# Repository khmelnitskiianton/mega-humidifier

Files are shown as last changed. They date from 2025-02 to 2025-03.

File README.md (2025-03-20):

# mega-humidifier



Проект умного увлажнителя воздуха.

Сделан для курсов "Практикум по цифровому производству" и "Микроконтроллеры" в МФТИ ФРКТ 4 семестр.

**Команда:**

- Хмельницкий Антон Б01-306
- Шилов Артем Б01-306
- Багацкий Дмитрий Б01-301

**Медиа:**

- [Github](https://github.com/khmelnitskiianton/mega-humidifier)
- [Telegram Channel](https://t.me/vapegoida)

Poster

## Цель проекта

Разработка автоматического увлажнителя для улучшения микроклимата в квартире

## Задачи проекта

1. Изучить теоретическую литературу по данному вопросу.
2. Изучить существующие аналоги.
3. Продумать и создать модель испарителя.
    + Разработать конструкцию данного устройства и необходимые элементы взаимодействия с окружающей средой.
    + Провести расчеты характеристик модели.
    + Подобрать нужные материалы.
    + Собрать модель.
4. Провести испытание полученного устройства.
5. Рассчитать производительность и КПД устройства с помощью данных полученных
экспериментально.
6. Улучшить устройство с учётом ошибок начальной версии.
7. Разработать технику безопасности и инструкцию по пользованию прибором.
8. Сравнить характеристики самодельного прибора с магазинным экземпляром.
9. Сделать выводы, продумать дальнейшее усовершенствование модели.

## Инструкция/Функционал:

1. Включить в сеть электропитания.
2. Проверить экран на наличие вывода данных и включения вентилятора и испарителя. 
3. На экран выводится: реальное время, примерное время окончания работы цикла
увлажнителя, показания влажности и температуры.
4. Запуск увлажнителя - фиксированное время. На паузу увлажнителем можно поставить нажатием кнопки, чтобы
продолжить работу нужно нажать её повторно. В это время будет выводится только реальное время и статус - “Пауза”.
5. Изменение скорости работы вентилятора и мощности испарения происходит за счет вращательного регулятора и тумблера.
6. По окончанию работы выводится сообщение об окончании и звучит оповещающий сигнал. Чтобы перезапустить увлажнитель и начать новую сессию, нужно нажать один раз на белую кнопку.

## Практическая часть

### Электрическая (модульная) часть

**Схема питания модулей:**

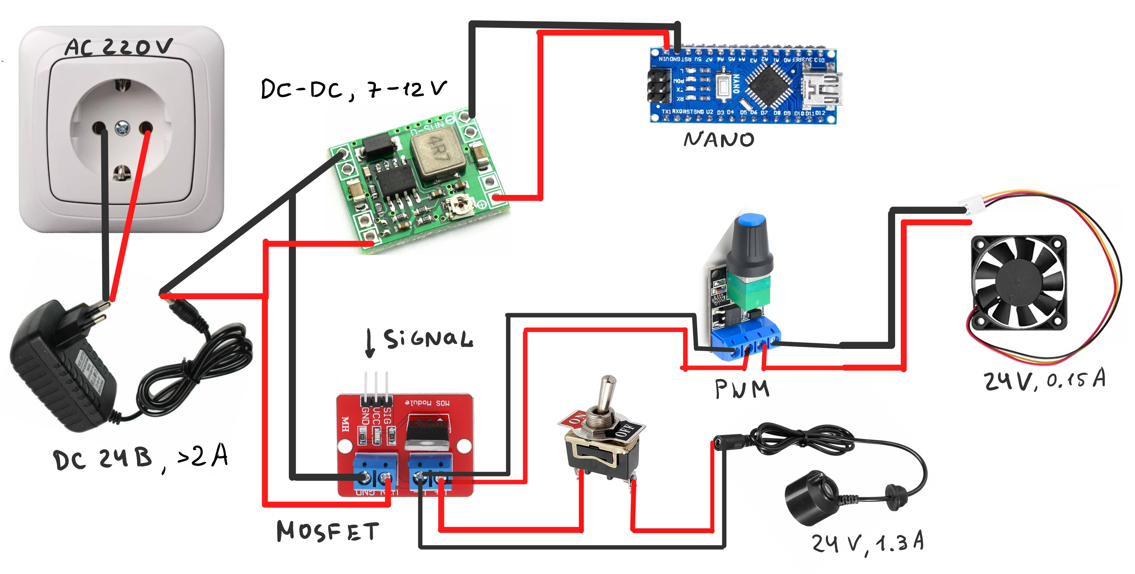
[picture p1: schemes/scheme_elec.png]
Схема питания


**[Схема](./schemes/scheme_arduino.fzz) (выполнена в Fritzing) подключения датчиков к Arduino Nano(лежит в `schemes/`):**

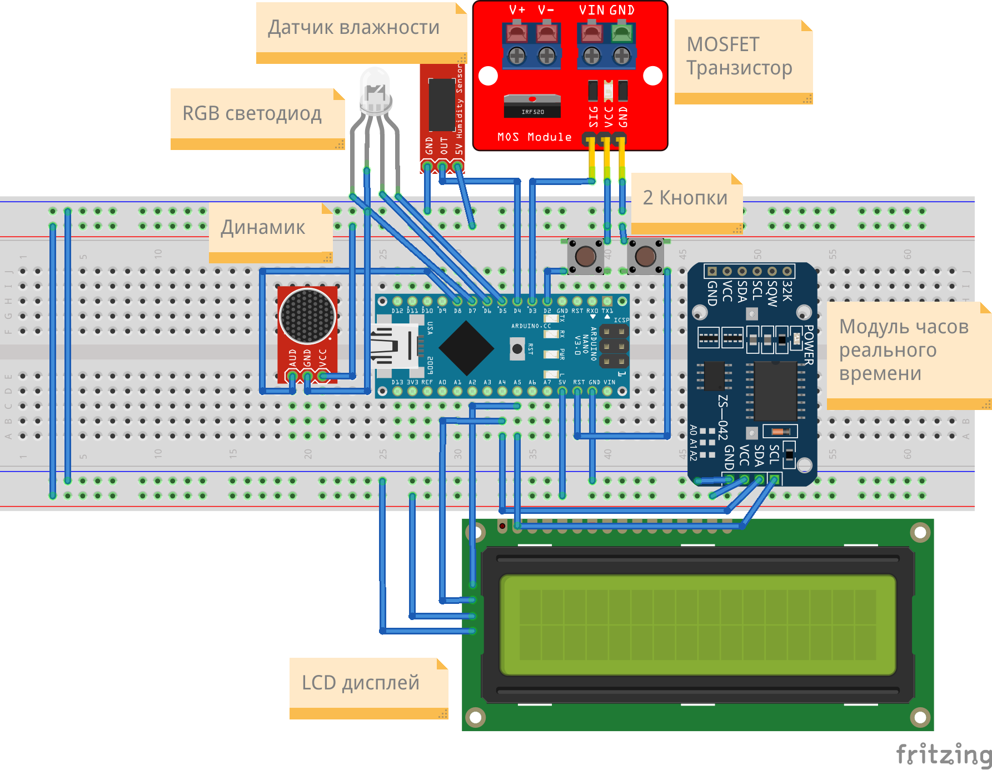
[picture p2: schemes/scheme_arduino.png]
Подключение датчиков


Питание всех модулей осуществляется через блок питания AC/DC IN: 100-200В, OUT: 24В & >2А.

Испаритель воды получает 24В (номинальные) при этом питание регулируется через тумблер. Также подача питания на него регулируется MOSFET транзистором. На вентилятор подается 24В через ШИМ и MOSFET транзистор.

Используется понижающий преобразователь DC-DC (в данном случае с 24В до 7-12В) для питания Arduino Nano .

**Датчики и элементы:**

+ Блок питания 24В, >2А
+ Arduino Nano
+ Вентилятор 24В (60x60x25)
+ Ультразвуковой испаритель 24В
+ Светодиодный модуль KY-016
+ Звуковой модуль KY-006
+ MOSFET транзистор IRF520N
+ ШИМ регулятор XK-1074
+ Тумблер ON-OFF (2A+ 24V+) 
+ Датчик влажности DHT11
+ Тактовая кнопка KY-004 x2
+ DC-DC преобразователь MP1584
+ Модуль реального времени RTC DS3231
+ Дисплей LCD 2004 I2C
 
[Код](./scripts/main/main.ino) прошивки выполнен в программе Arduino IDE(исходный код в `scripts/main/`).

**Использовались библиотеки(лежит в `libs/`):** 

- [для модуля часов реального времени RTC](https://github.com/adafruit/RTClib/releases/tag/1.14.2)
- [для датчиков влажности](https://istarik.ru/blog/arduino/35.html)
- [для дисплея с шиной I2C](https://iarduino.ru/file/134.html)
- [для использования шины I2C(стандартная)](https://docs.arduino.cc/language-reference/en/functions/communication/wire/)

**Основные функции и задачи Arduino:**

1. Управление работой увлажнителя (а именно испарителя и вентилятора) с помощью MOSFET транзисторов.
2. Создание интерфейса для более удобного управления пользователем увлажнителя с
помощью вывода информации на дисплей и управления модулями с помощью кнопок и регуляторов.
3. Измерение и мониторинг показателей микроклимата в квартире (влажность и
температура).
4. Контроль работы с помощью индикации, а также сигнализировании пользователя о завершении работы с помощью звукового модуля.

**Описание кода:**

1. Использованные библиотеки: для датчика влажности (`stDHT.h`), для дисплея
(`LiquidCrystal_I2C.h`), для модуля часов реального времени (`RTClib.h`) и
стандартная библиотека (`Wire.h`).
2. Для большинства модулей написаны отдельные функции: для датчика влажности,
для MOSFET и пьезоэлемента, для модуля часов реального времени.
3. Процесс представляет из себя лимитированная по времени сессия работы. В коде
прописывается время продолжительности работы и автоматически после
определенного времени увлажнитель отключает нагреватель и выводит на экран
надпись `END OF SESSION. PRESS <RESET>`. Чтобы обновить сессию и
заново запустить процесс, нужно нажать на отдельную кнопку Reset.
4. В процессе работы увлажнителя на дисплей выводится реальное время и показания
влажности и температуры, а также время до конца сессии (работы увлажнителя).
Также есть индикация (светодиод), который светит красным цветом или зеленым в
зависимости от того оптимальная ли влажность или нет. Границы также
можно указать в коде.
5. Реализована функция "Паузы", т.е. можно нажатием кнопки Button приостановить
(и продолжить повторным нажатием) работу испарителя и вывод данных на
дисплей. Таким образом можно остановить работу увлажнителя простым нажатием
кнопки на неопределенное время. В процессе паузы выключены реле, светодиод
горит синим цветом и на дисплее выводится надпись `PAUSE` и время с количеством оставшегося времени.

Параметры для настройки работы увлажнителя находятся в [setup.inc](./scripts/main/setup.inc), можно настроить:

- Время работы увлажнителя.
- Минимальную/максимальную допустимую влажность.
- Длительность и тон писка.

**Демонстрация электроники:**

[Видео](https://github.com/user-attachments/assets/03b7d397-51f3-43c1-a0f4-bfc7255fe9b3)

### Конструкционная (механическая) часть

**Контейнер:**

Были изучены аналоги увлажнителей и выбран вариант сборки всех частей в
одной ёмкости. Ёмкость представляет из себя пластиковый контейнер, с высокими стенками и
ручками, вместимость - 4.5 литра размером 17.5x17x21 см

В крышке контейнера вмонтирован вентилятор (60x60x15 см) для вентиляции и создания
нагнетания воздуха. Таким образом поток воздуха насыщается водой, проходя через
увлажнитель, и испаряясь выходит из увлажнителя. Также вмонтирована направляющая конструкция(60x60x15 см), чтобы пар выходил под углом 45 градусов.

**Крышка и корпус:**

Электроника размещена в отдельной пластиковом корпусе с вырезом для дисплея и выведенными на бок датчиками и кнопками. 
Кнопки размещены на корпусе и прикреплены винтами М2.5.

Корпус для электроники, а также направляющая конструкция были смоделированы в SolidWorks/Компас3D (исходники в `enclosure/SLDPRT/` и `enclosure/STL/`), а затем распечатаны на 3D принтере. Отверстия вырезались с помощью дремеля или были смоделированы при проектировании корпуса перед печатью.

**Печатная плата:**

Была смоделирована (исходники в `plate/`) печатная плата для сборки всех датчиков с помощью KiCad и FlatCam и вырезана на фрезерном станке Charly4U:

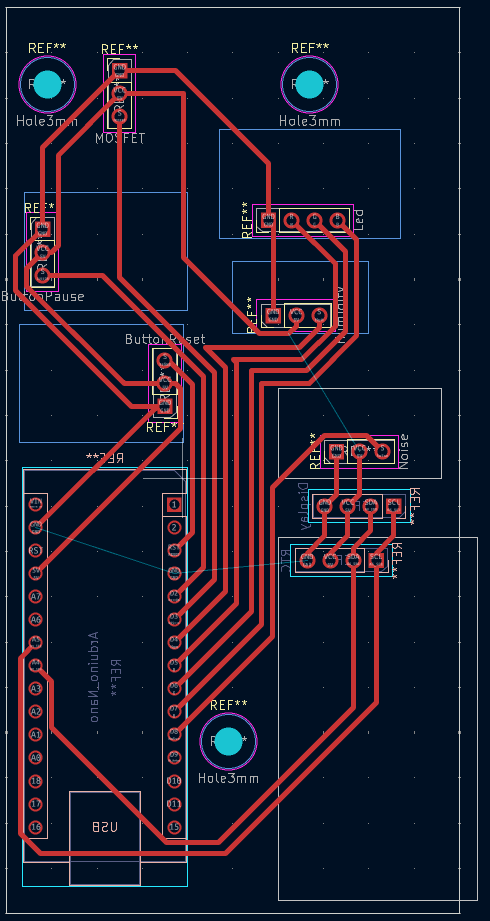
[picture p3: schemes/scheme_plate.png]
Схема платы


- Все датчики монтируются непосредственно либо на плате(односторонняя, но крепятся датчики с двух сторон), либо отдельно проводами.
- Сделаны 3 отверстия для монтажа платы к корпусу винтами M3.

**Таблички с гравировкой**:

Были смоделированы (исходники в `cut/`) таблички с названиями всех элементов на корпусе для упрощения использования устройства в программе CorelDRAW и вырезаны на лазерном станке GCC Spirit GLS40. Затем размещены на корпусе с помощью жидкого клея.

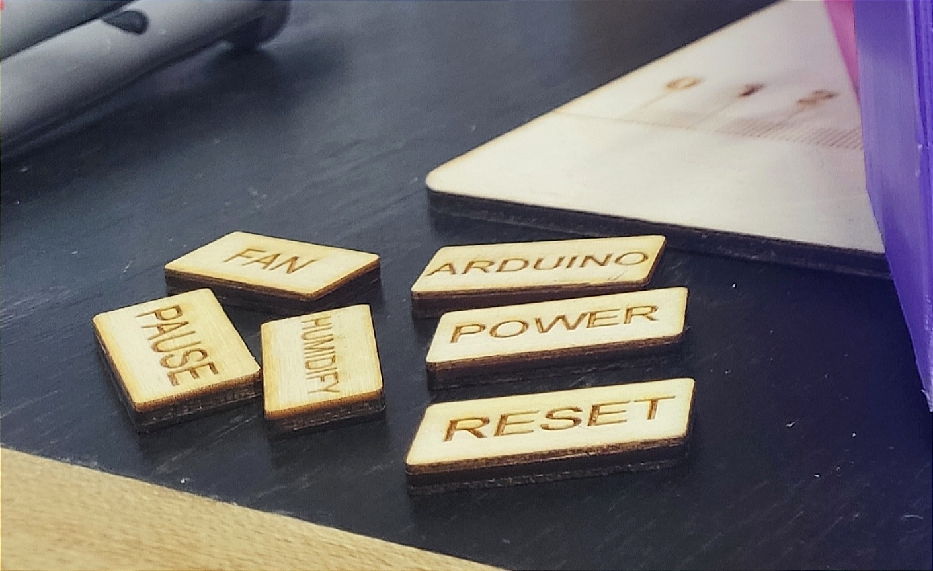
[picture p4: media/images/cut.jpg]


## Процесс сборки

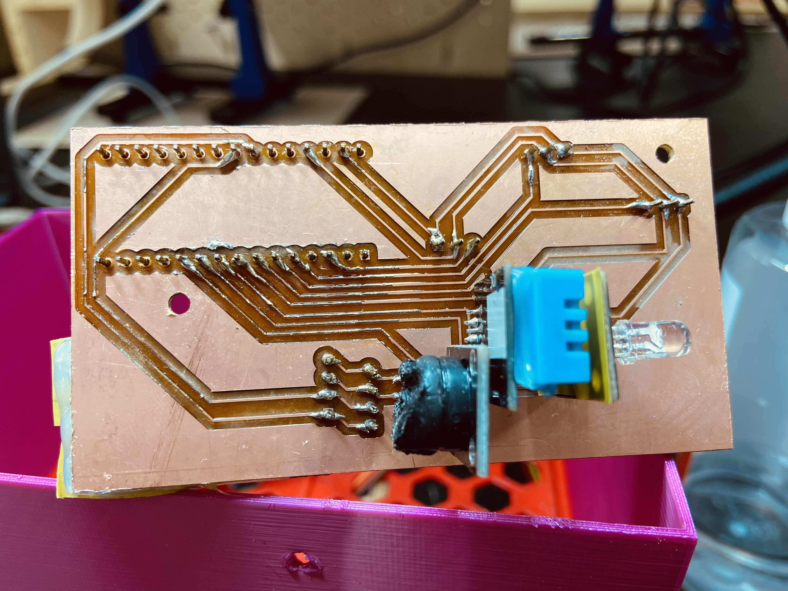
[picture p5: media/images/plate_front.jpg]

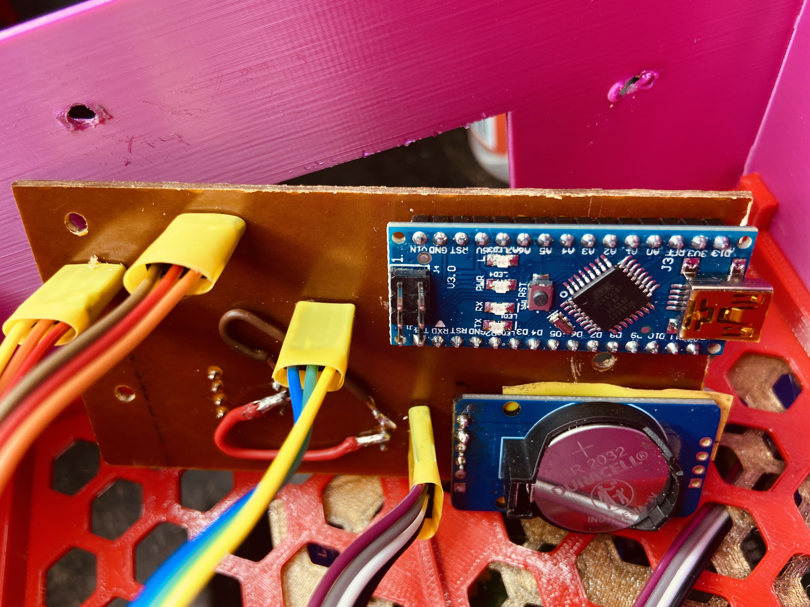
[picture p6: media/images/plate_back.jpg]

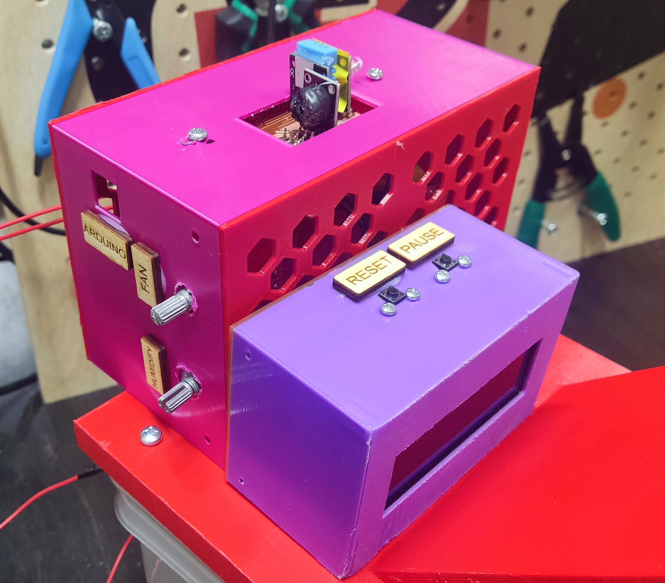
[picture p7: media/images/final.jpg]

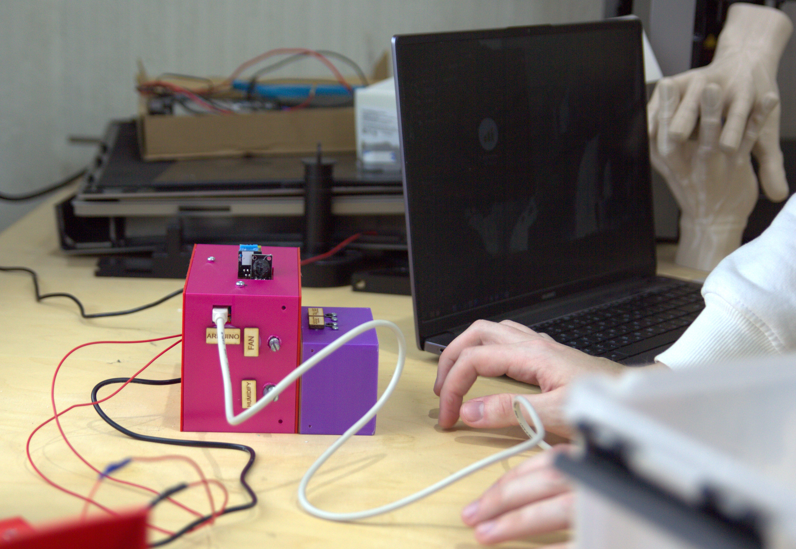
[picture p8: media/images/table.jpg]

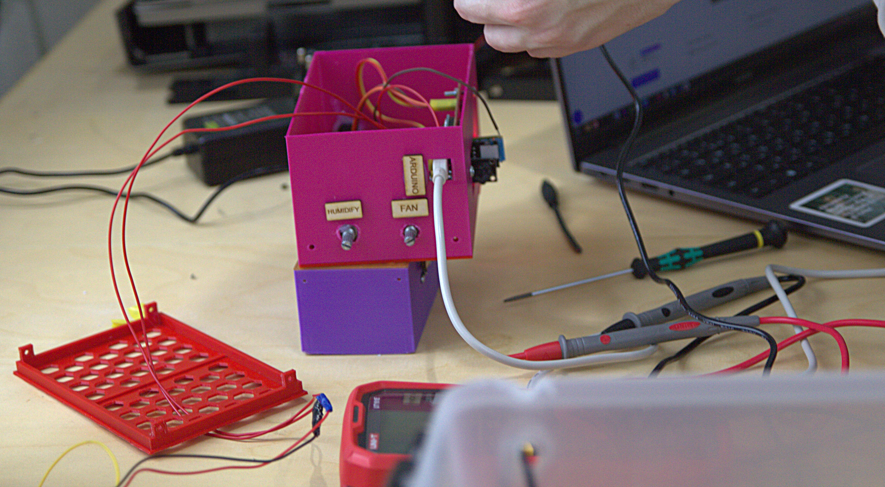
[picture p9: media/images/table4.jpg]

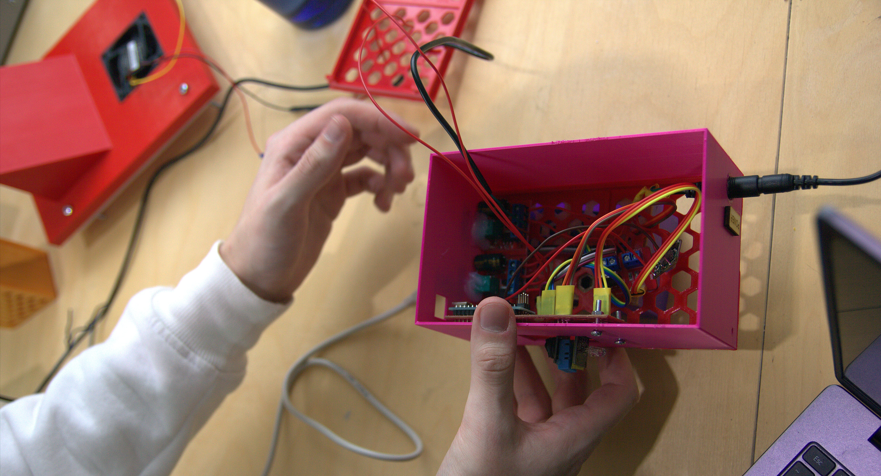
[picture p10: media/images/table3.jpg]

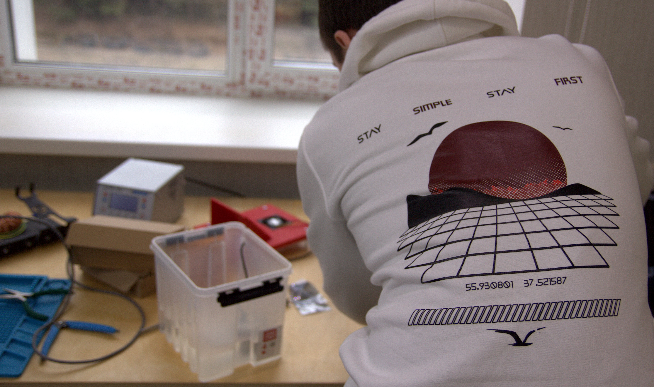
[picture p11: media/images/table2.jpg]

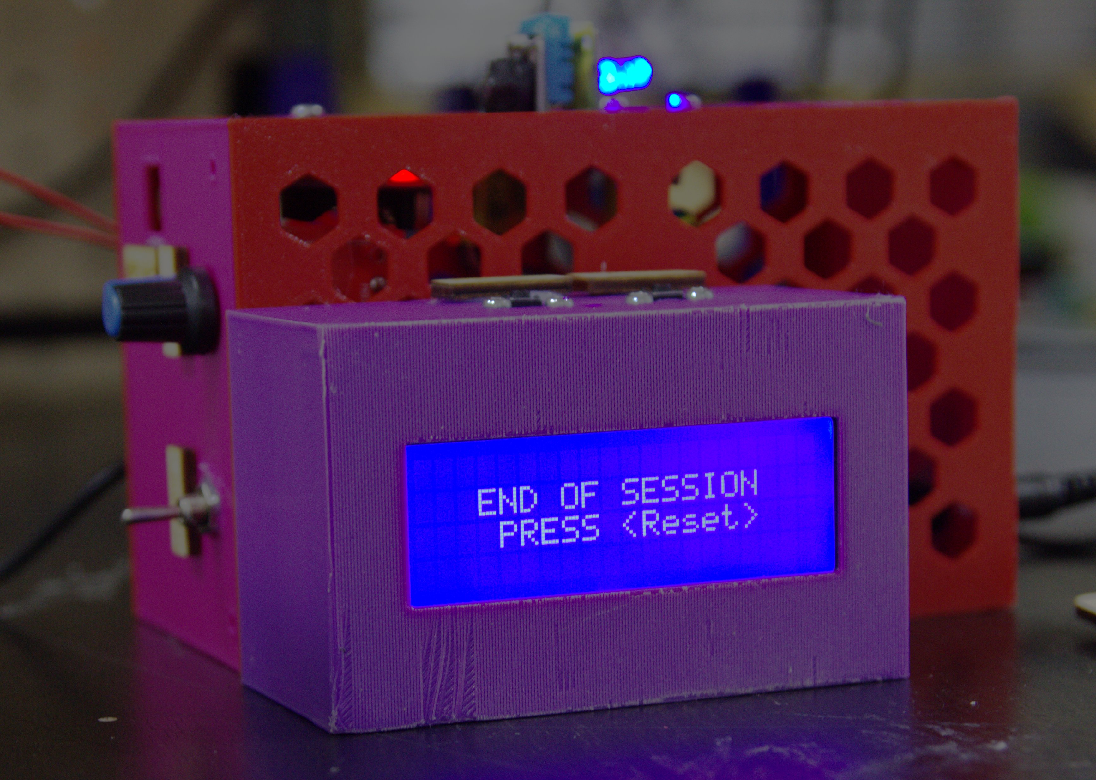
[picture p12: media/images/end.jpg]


**Демонстрация работы(`media/final.mp4`)**:

[Видео](https://github.com/user-attachments/assets/1c645f1c-7396-49a5-b0d6-75ca31a28341)

## Экспериментальный расчет

Производительность парогенератора: 450 мл/ч

Емкость рассчитана на 4.5л, с учетом датчика уровня воды встроенного в парогенератор, эффективный объем воды для испарения 2.5л.

Получаем примерную длительность работы увлажнителя - 5.5ч. 

Рекомендованная настройка работы увлажнителя - 5ч.

## Сравнение с аналогами

Примерная цена всех компонентов: 3500 руб, что меньше чем цена за аналоги с меньшим функционалом.

- [AlexGyver Humidifier](https://github.com/AlexGyver/autoHumidifier) - рядом не стояло.
- [Ivan9073 Youtuber](https://www.youtube.com/watch?v=dj69xXlSA7M) - в подметки не годится.
- [Dzen RMNT.RU](https://dzen.ru/a/ZfLKBk9sOwf64ch5) - слабо.
- [Алексей Федосенко Youtuber](https://www.youtube.com/watch?v=r24A2fugexM) - детский сад.
- [VITEK VT-2348](https://ozon.ru/t/ggRDX7P) - больший функционал, дешевле.

## Результаты и выводы

В ходе разработки автоматического увлажнителя воздуха были выполнены все основные этапы проектирования и сборки устройства.

1. Функциональность устройства

Увлажнитель успешно выполняет свою основную функцию – насыщает воздух влагой с регулируемыми параметрами интенсивности испарения и вентиляции.
Система управления через Arduino Nano позволяет контролировать показатели микроклимата (температуру и влажность), а также задавать параметры работы устройства.
Реализован удобный пользовательский интерфейс с дисплеем, кнопками и регуляторами.
Встроены индикация и звуковой сигнал, что повышает удобство эксплуатации.

2. Эффективность увлажнения

Производительность парогенератора составила 450 мл/ч, что позволяет устройству работать в течение 5,5 часов на одном полном резервуаре (эффективный объем 2,5 л). Также есть возможность расширения объема использовав емкость с большим объемом.
Экспериментальные замеры показали, что устройство способно поддерживать уровень влажности в помещении на оптимальном уровне (40-60%) в зависимости от настроек.

3. Сравнение с аналогами

В сравнении с коммерческими моделями устройство показало схожие характеристики по производительности, но с возможностью гибкой настройки режимов работы.
Стоимость самодельного увлажнителя оказалась ниже аналогичных готовых устройств, что делает проект экономически оправданным.

4. Конструкционные и инженерные решения

Использование 3D-печати позволило создать компактный корпус и направляющую конструкцию для выхода пара.
Электронные компоненты были успешно интегрированы на печатную плату, что упростило сборку и повысило надежность системы.
Устройство собрано из доступных компонентов, что делает возможным его дальнейшее усовершенствование.

5. Возможные улучшения

В будущем можно реализовать автоматическое отключение при достижении заданного уровня влажности.
Возможно добавление управления через Wi-Fi/мобильное приложение для удаленного контроля и мониторинга.
Можно усовершенствовать систему подачи воды, чтобы увеличить время автономной работы.

## Вывод

Созданный умный увлажнитель воздуха соответствует поставленным требованиям и демонстрирует высокую эффективность в поддержании комфортного уровня влажности в помещении. Проект успешно прошел этап испытаний, подтвердил свою работоспособность и может быть доработан в будущем для повышения удобства использования и расширения функционала.

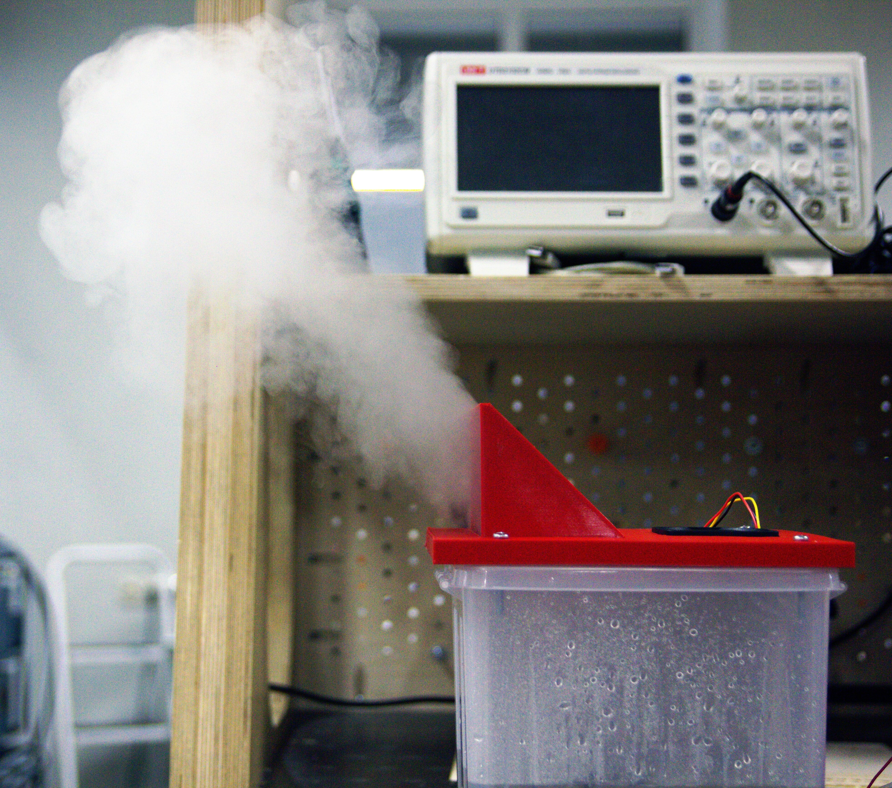
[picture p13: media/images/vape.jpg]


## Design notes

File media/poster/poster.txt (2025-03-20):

(Заголовок):
Автоматический увлажнитель воздуха для поддержания комфортного микроклимата в помещении. Устройство контролирует уровень влажности, регулирует интенсивность испарения и работает по заданному пользователем времени. Компактная конструкция с цифровым управлением делает его удобным в эксплуатации.

Функционал устройства:
• Автоматическое поддержание влажности
• Регулируемая мощность испарителя и вентилятора
• Дисплей с отображением текущей влажности, температуры и времени работы
• Звуковая и световая индикация
• Функция паузы
• Простая перезагрузка работы

Комплектующие:
• Блок питания 24В, >2А
• Arduino Nano
• Вентилятор 24В (60x60x25)
• Ультразвуковой испаритель 24В
• Светодиодный модуль KY-016
• Звуковой модуль KY-006
• MOSFET транзистор IRF520N
• ШИМ регулятор XK-1074
• Тумблер ON-OFF (2A+ 24V+) 
• Датчик влажности DHT11
• Тактовая кнопка KY-004 x2
• DC-DC преобразователь MP1584
• Модуль реального времени RTC DS3231
• Дисплей LCD 2004 I2C

Конструкция:
• Два корпуса для электроники, напечатанный на 3D-принтере
• Контейнер 4,5 л с вмонтированным вентилятором
• Направляющая для выхода пара

Принцип работы:
• Контроль микроклимата – датчик DHT11 измеряет температуру и влажность, передавая данные в систему управления.
• Испаритель и вентилятор – регулируемые питанием позволяют настраивать скорость увлажнения.
• Индикация – дисплей LCD 2004 I2C отображает состояние увлажнителя, а цвет светодиода информирует о статусе работы.
• Автоматическое отключение – по окончании заданного времени устройство выключается и подает сигнал.

Используемые технологии:
• 3D-печать
• Лазерная резка
• Фрезерная резка
• Пайка
• Прошивка микроконтроллера(Arduino)

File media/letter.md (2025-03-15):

# Пояснительная записка к проекту "Умный увлажнитель воздуха"

Github: [https://github.com/khmelnitskiianton/mega-humidifier](https://github.com/khmelnitskiianton/mega-humidifier)

## Автор и состав проектной команды

Проект разработан в рамках курсов "Практикум по цифровому производству" в МФТИ ФРКТ (4 семестр).

### Команда разработчиков:

- Хмельницкий Антон (Б01-306) – работа с микроконтроллером, проектирование и работа с печатной платой.
- Шилов Артем (Б01-306) –  подбор комплектующих, 3D моделирование и печать, организация сборки и тестирования.
- Багацкий Дмитрий (Б01-301) – механическая часть устройства, модулирование в граф. редакторе, работа с ЧПУ и лазерной резкой.

## Причины выбора проекта
 
Уровень влажности в помещении напрямую влияет на здоровье человека и комфорт проживания. Недостаточная влажность может приводить к сухости кожи, проблемам с дыхательной системой, ухудшению состояния растений и мебели. Коммерческие модели увлажнителей воздуха зачастую имеют ограниченный функционал, высокую стоимость или низкую эффективность.

Наш проект предлагает создание автоматического увлажнителя, который будет поддерживать заданный уровень влажности, обеспечивать удобный пользовательский интерфейс и предоставлять больше возможностей для гибкой настройки по сравнению с аналогами.

## Цель и задачи проекта

### Цель

Разработка автоматизированного увлажнителя воздуха с интеллектуальным управлением и возможностью гибкой настройки параметров работы.

### Задачи

- Исследование существующих аналогов и теоретической литературы по теме.
- Разработка модели испарителя, подбор материалов и проведение расчетов.
- Проектирование и сборка схемы питания и управления устройством.
- Разработка программного обеспечения для управления устройством.
- Проведение испытаний и тестирование производительности.
- Оптимизация устройства, исправление недостатков.
- Разработка инструкции по эксплуатации.
- Сравнение характеристик устройства с коммерческими аналогами.

##  Описание устройства

Умный увлажнитель воздуха представляет собой устройство, которое автоматически регулирует уровень влажности в помещении. 

Оно состоит из следующих компонентов:

+ Блок питания: 24В, >2А
+ Контроллер: Arduino Nano.
+ Испаритель: 24В с регулировкой подачи питания.
+ Вентилятор: 24В с ШИМ-регулированием.
+ Датчик влажности и температуры: DHT11.
+ Дисплей LCD 2004 I2C: отображает текущее состояние устройства.
+ Модуль реального времени RTC DS3231: позволяет учитывать время работы и отображать реальное время.
+ 2 кнопки управления, MOSFET транзистор, RGB светодиод: управление работой увлажнителя и индикация состояния.

### Функции устройства:

+ Автоматическое включение и выключение по таймеру.
+ Регулировка интенсивности испарения и скорости вентиляции.
+ Отображение текущих данных на дисплее.
+ Звуковая индикация окончания работы.
+ Возможность временной паузы и ручного управления.

##  Процесс решения поставленных задач

### Электронная часть

Проектирование схемы проводилось с использованием Fritzing.

Код был разработан в среде Arduino IDE. Исходники в `scripts/main/`

Использованы библиотеки:

+ `RTClib.h` – для работы с модулем реального времени.
+ `stDHT.h` – для работы с датчиком влажности.
+ `LiquidCrystal_I2C.h` – для управления дисплеем.
+ `Wire.h` – для работы с I2C-шиной.

Функциональность кода:

+ Чтение данных с датчика влажности и температуры.
+ Управление вентилятором и испарителем через MOSFET.
+ Отображение параметров на дисплее.
+ Реализация режима паузы и индикации.

### Механическая часть

Корпус для электроники и направляющая конструкция для выхода пара были смоделированы в SolidWorks/Компас3D и напечатаны на 3D-принтере. Электронные компоненты размещены в пластиковом корпусе с креплением кнопок и дисплея. Исходники в `enclosure/`

Печатная плата была разработана в KiCad и вырезана на фрезерном станке Charly4U. Исходники в `plate/`

## Анализ аналогов и отличительные особенности

Аналоги на рынке:

+ VITEK VT-2348 – имеет меньший функционал и слабую систему управления.
+ AlexGyver Humidifier – не обладает удобным интерфейсом и дисплеем.
+ DIY-проекты с YouTube – часто не имеют автоматизации и гибких настроек.

### Отличительные особенности нашего устройства:

+ Полноценный дисплей с отображением данных.
+ Гибкое управление скоростью испарителя и вентилятора.
+ Звуковая индикация завершения работы.
+ Возможность временной паузы.
+ Компактный корпус с удобным доступом ко всем элементам.

## Процесс проектирования и изготовления

+ Разработка схемы подключения и выбор компонентов.
+ Проектирование печатной платы в KiCad и её производство.
+ Создание 3D-модели корпуса и печать деталей на 3D-принтере.
+ Создание табличек с гравировкой в CorelDraw и вырезание их на лазерном станке.
+ Сборка устройства, проверка работы всех компонентов.
+ Написание кода управления, отладка программного обеспечения.
+ Проведение тестирования и внесение корректировок.

## Тестирование и анализ результатов

Производительность парогенератора – 450 мл/ч.
Объем резервуара – 4.5 л (эффективно используется 2.5 л).
Время работы – до 5.5 часов на одной заправке.
Оптимальный уровень влажности поддерживается в пределах 40-60%.
Испытания показали, что устройство стабильно работает, поддерживая заданные параметры влажности.

## Выводы

Разработанный умный увлажнитель воздуха полностью соответствует поставленным целям. Он обеспечивает удобное управление, надежную работу и гибкую настройку параметров. По сравнению с коммерческими аналогами, он обладает большим функционалом при меньшей стоимости.

### Потенциальные улучшения:

+ Добавление Wi-Fi-модуля для дистанционного управления.
+ Автоматическое отключение при достижении заданной влажности.
+ Расширение резервуара для увеличения времени автономной работы.
+ Проект успешно завершен, протестирован и может быть использован в реальных условиях.

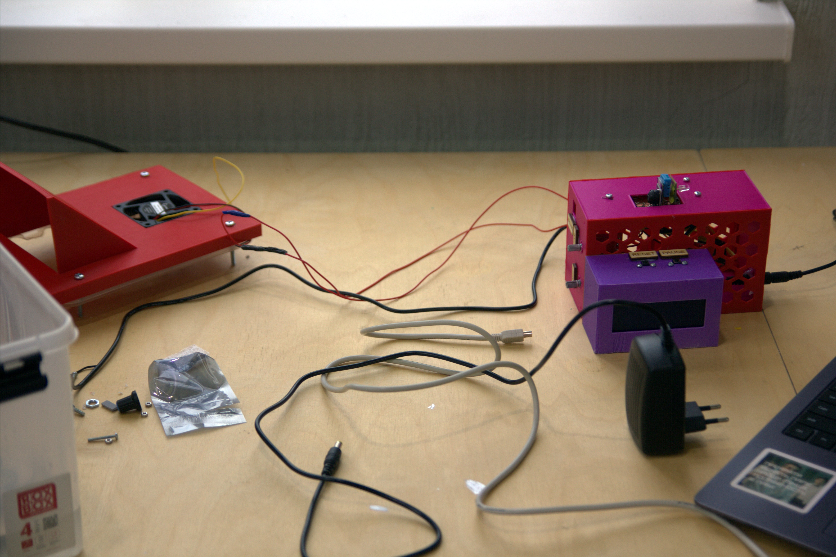
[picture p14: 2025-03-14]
media/images/made.jpg

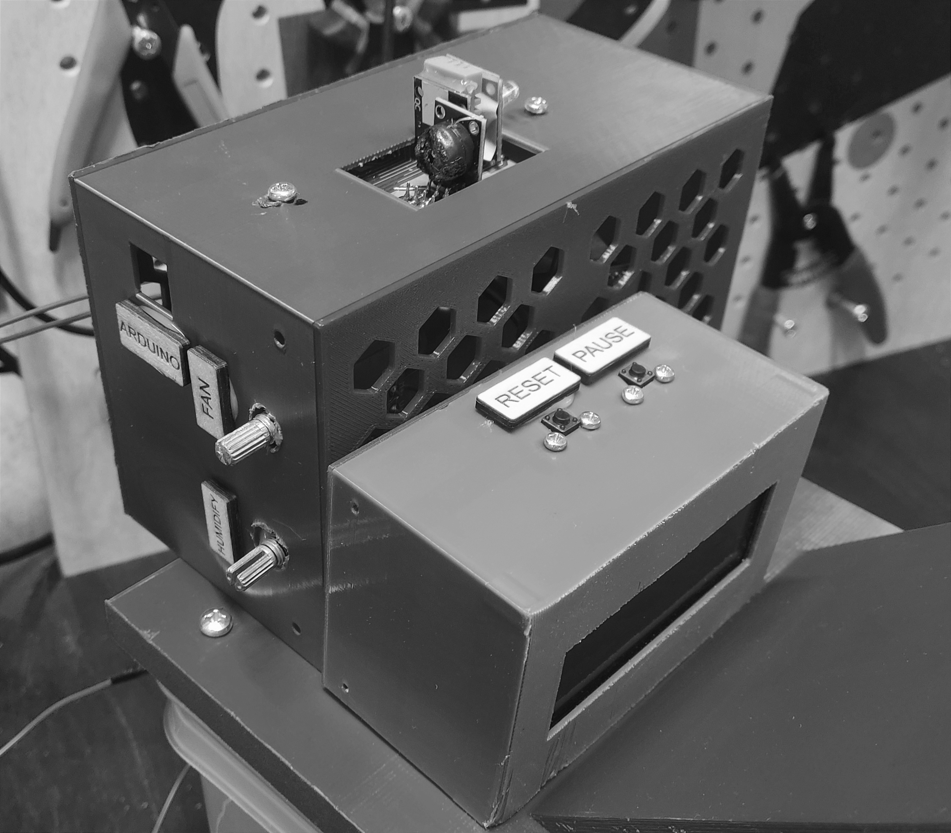
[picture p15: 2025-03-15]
media/images/final_bw.jpg

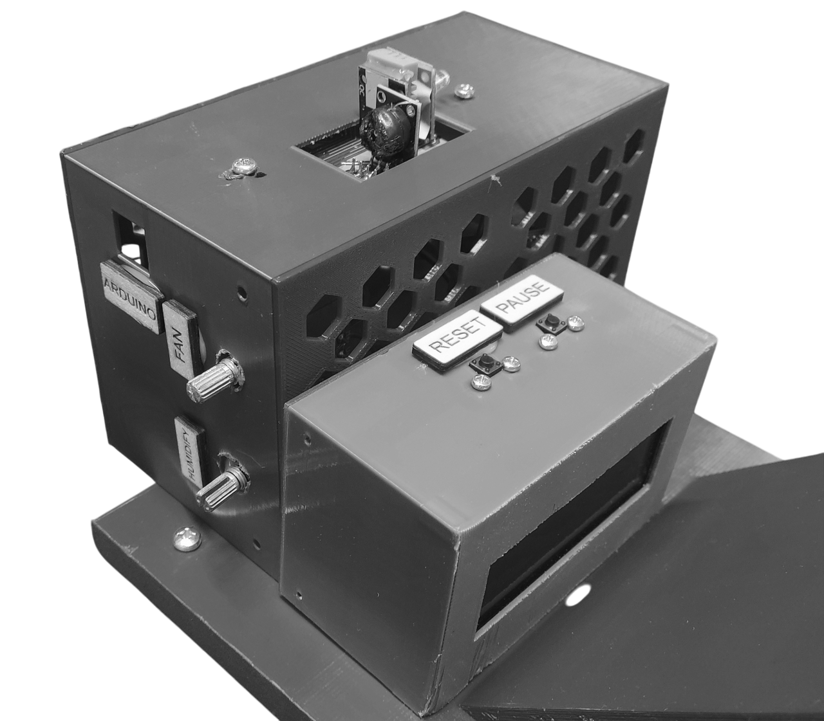
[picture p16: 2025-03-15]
media/images/final_bw_cut.png

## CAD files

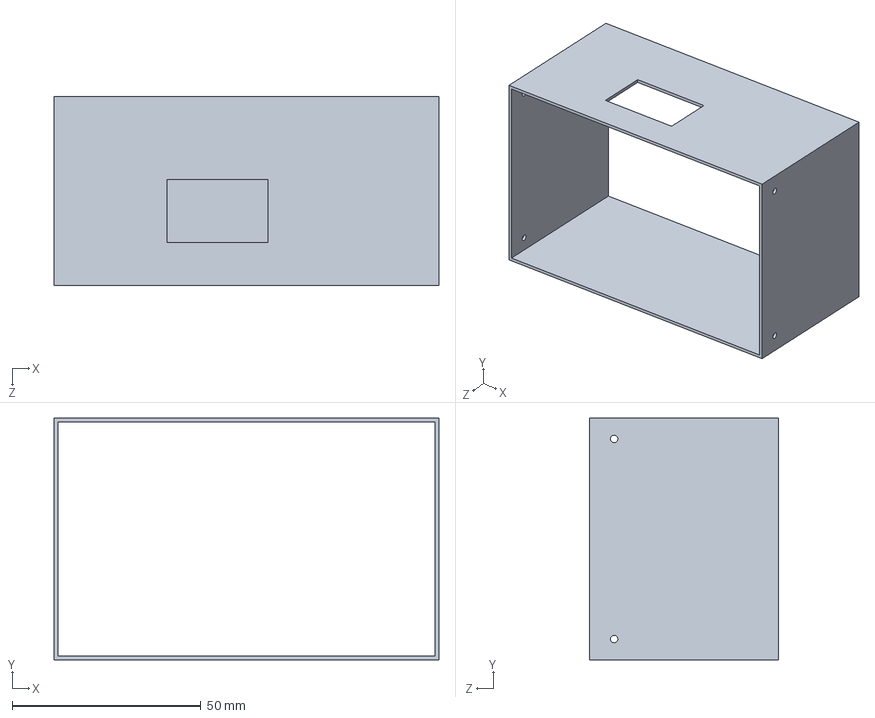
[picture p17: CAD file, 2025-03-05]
enclosure/SLDPRT/box_1.5x_holes.SLDPRT
102.0 x 64.0 x 50.0 mm

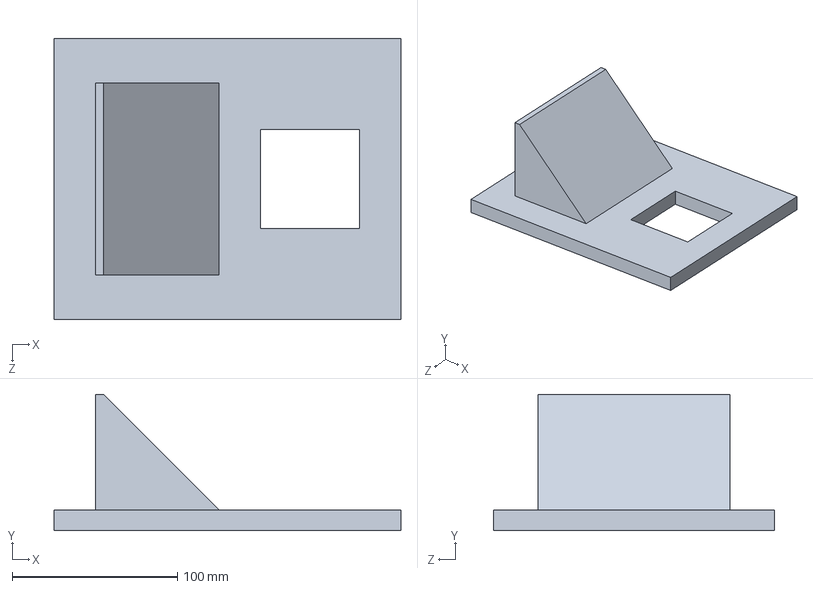
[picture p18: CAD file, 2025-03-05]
enclosure/SLDPRT/head.SLDPRT
210.0 x 82.5 x 170.0 mm

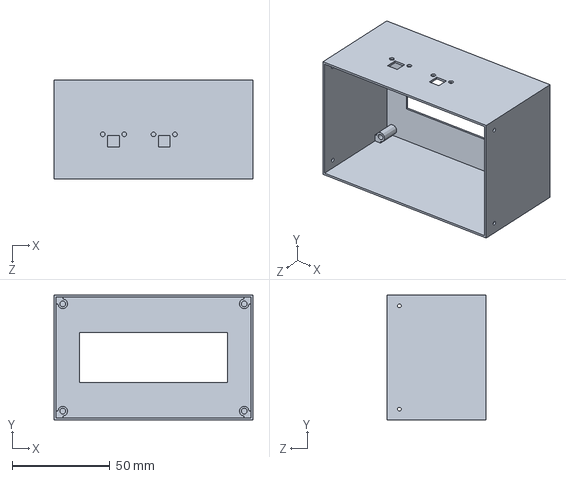
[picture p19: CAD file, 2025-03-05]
enclosure/SLDPRT/box_buttons.SLDPRT
102.0 x 64.0 x 51.0 mm

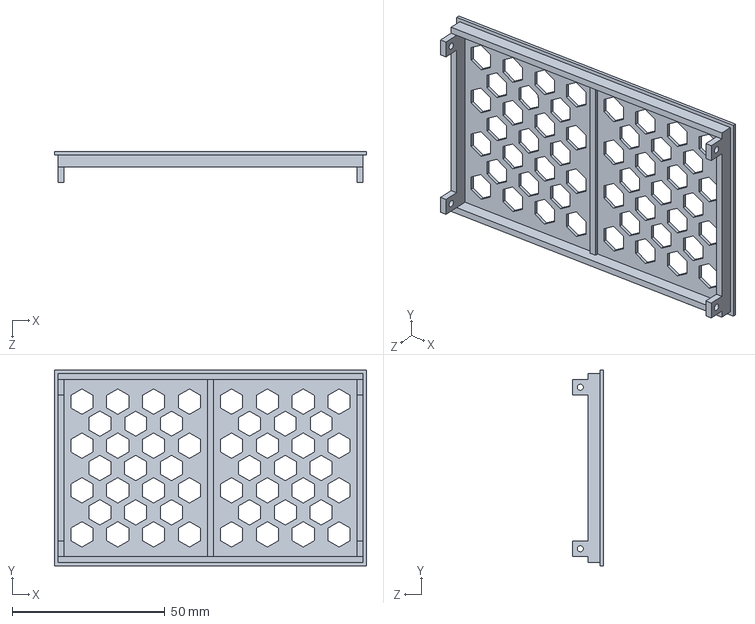
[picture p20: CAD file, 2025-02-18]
enclosure/SLDPRT/box_close.SLDPRT
102.0 x 64.0 x 10.0 mm

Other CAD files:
enclosure/SLDPRT/box_display.SLDPRT
enclosure/STL/box_1.5x_holes.STL
enclosure/STL/box_buttons.STL
enclosure/STL/box_close.STL
enclosure/STL/box_display.STL
enclosure/STL/head.STL

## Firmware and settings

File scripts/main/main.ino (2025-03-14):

#include <Wire.h>               // Подключаем библиотеку для работы с шиной I2C
#include <stDHT.h>              // Подключаем библиотеку для работы с датчиком влажности DHT11
#include <LiquidCrystal_I2C.h>  // Подключаем библиотеку для работы с LCD дисплеем по шине I2C
#include <RTClib.h>

// Файл с параметрами работы увлажнителя
#include <setup.inc>

RTC_DS3231 rtc;
char daysOfTheWeek[7][5] = {"Sun", "Mon", "Tue", "Wed", "Thu", "Fri", "Sat"};
      
LiquidCrystal_I2C lcd(0x27,20,4);   // Объявляем  объект дисплея, указывая параметры дисплея (адрес I2C = 0x27, количество столбцов = 20, количество строк = 4)
                                    // Если надпись не появилась, замените адрес 0x27 на 0x3F
DHT sens(DHT11);  // Объявляем объект датчика влажности с указанием модели DHT11

// Номера пинов куда идёт подключение разных датчиков
//====================================================
#define light_pin_red 5     // пин красного светодиода
#define light_pin_green 6   // пин зеленого светодиода
#define light_pin_blue 7    // пин голубого светодиода
#define relay_pin 3         // пин MOSFET
#define sensor_pin 4        // пин датчика
#define sound_pin 8         // пин пищалки 
#define button_pin 2        // пин кнопки
//====================================================

// Глобальные переменные
uint32_t tim, end_tim;         
boolean butt_flag = 0;      // флажок нажатия кнопки
boolean butt;               // переменная, хранящая состояние кнопки
boolean flag = 0;           // флажок режима
unsigned long last_press;   // таймер для фильтра дребезга
boolean condition = 0;      
boolean final_end = 0;
unsigned long s_last_time = last_time / 1000; // время до отключения(увеличивается, если ставить на паузу) (с)
unsigned long end_time, start_time;

void setup() 
{
  Serial.begin(9600);
  lcd.init();           // Инициируем работу с LCD дисплеем
  lcd.backlight();      // Включаем подсветку LCD дисплея

  // Обнаружение RTC
  if (!rtc.begin()) {
    Serial.println("Couldn't find RTC");
    Serial.flush();
  }
  
  // Инициализация и установка времени на rtc в формате (год,месяц,день,часы,минуты,секунды)
  /*
   * Note: При первой загрузке - измените аргументы DataTime на текущее время.
   * При повторной загрузке - закомментируйте эту строку 
   * (в противном случае время будет сбрасываться после каждой перезагрузке ардуино).
  */
  rtc.adjust(DateTime(2025, 3, 14, 15, 30, 0));

  // Set all pins
  pinMode(sensor_pin, INPUT);
  digitalWrite(sensor_pin, HIGH);
  pinMode(light_pin_red, OUTPUT);       // red
  pinMode(light_pin_green, OUTPUT);     // green
  pinMode(light_pin_blue, OUTPUT);      // blue
  pinMode(button_pin, INPUT_PULLUP);    // кнопка подтянута внутренним резистором (урок 5)
  pinMode(relay_pin, OUTPUT);           // пин реле как выход
  digitalWrite(relay_pin, HIGH);        // сразу активируем MOSFET
  delay(1000);
}

void loop() 
{
  if (condition == 0) {
    stop_relay_sound();  // проверка реле
  }
  if(final_end == 0) {  // если ещё не конец, то выводим время
    real_time(); 
  }
  
  // Далее блок паузы
  butt = !digitalRead(button_pin);  // считать текущее положение кнопки
  if (butt == 1 && butt_flag == 0 && millis() - last_press > 100 && final_end == 0) {  // если кнопка НАЖАТА, до этого была ОТПУЩЕНА
    if (flag == 0){
      start_time = millis();
      digitalWrite(relay_pin, LOW);
    } else {
      end_time = millis();
      digitalWrite(relay_pin, HIGH);
    }
    butt_flag = 1;          // запоминаем, что нажимали кнопку
    flag = !flag;           // инвертируем флажок
    last_press = millis();  // запоминаем время
	
    // Светодиод синий
    digitalWrite(light_pin_green, LOW);
    digitalWrite(light_pin_blue, HIGH);
    digitalWrite(light_pin_red, LOW);
    draw_pause();
    condition = flag;
    if (condition == 0){
      lcd.clear(); // При продолжении очищаем экран от текста паузы
    }
  }
  if (butt == 0 && butt_flag == 1 && final_end == 0) {  // если кнопка ОТПУЩЕНА, и до этого была НАЖАТА
    butt_flag = 0;                    // запоминаем, что отпустили кнопку
  } // Конец блока паузы
  
  // Проверка, что паузы нет и вывод всего
  if (condition == 0 && final_end == 0){
    humidity();
    deadlain_time();
  }

  // Увеличение времени отключения после паузы
  if (butt == 0 && butt_flag == 0 && flag == 0){
    last_time = last_time + end_time - start_time;
    end_time = 0;
    start_time = 0;
  }
  
}

// функция измерения влажности и температуры (и отображение)
void humidity(){
  int t = sens.readTemperature(sensor_pin); // чтение датчика на пине sensor_pin
  int h = sens.readHumidity(sensor_pin);
  if (h <= max_hum and h >= min_hum){   // изменение цвета светодиода в зависимости от "хорошей" влажности
      // Светодиод зеленый	      
      digitalWrite(light_pin_green, HIGH);
      digitalWrite(light_pin_blue, LOW);
      digitalWrite(light_pin_red, LOW);
  } else {
      // Светодиод красный
      digitalWrite(light_pin_red, HIGH);
      digitalWrite(light_pin_green, LOW);
      digitalWrite(light_pin_blue, LOW);
  }
  if(end_tim > 1){
      // Вывод статистики
      lcd.setCursor(5, 2);
      lcd.print("Hum: ");
      lcd.print(h);
      lcd.print("%  ");
      lcd.setCursor(4, 3);
      lcd.print("Temp: ");
      lcd.print(t);
      lcd.print((char)223); // Цельсий  
      lcd.print("C  ");
      
      Serial.print("Hum: ");
      Serial.print(h);
      Serial.print(" T: ");
      Serial.println(t);
  } 
}

// функция отключения питания
void stop_relay_sound(){
  if((millis() - last_time >= 0) && (millis() - last_time <= 100)){
    digitalWrite(relay_pin, LOW); // Off питания
    tone(sound_pin, tone_sound);  // Звук окончания
    delay(sound_time);
    noTone(sound_pin);
  }
}

// функция вывода на дисплей сколько осталось до конца
void deadlain_time(){
    tim = millis();                     // Сколько прошло с момента включения (мс)
    end_tim = (last_time - tim)/1000;   // Сколько осталось (с)
    lcd.setCursor(0, 1);                // Устанавливаем курсор в позицию (0 столбец, 1 строка).
    lcd.print(" Time Rest: ");
    if (s_last_time >= end_tim && end_tim >= 7200){               // если осталось от 7 до 2 часов    
        lcd.print(end_tim / 3600);
        lcd.print(" hours  ");                                      
    } else if (end_tim < 7200 && end_tim >= 3600) {               // если остался 1 час
        lcd.print(end_tim / 3600);
        lcd.print(" hour  ");                                  
    } else if (end_tim < 3600 && end_tim >= 60) {                 // если остался меньше часа
        lcd.print(end_tim / 60);
        lcd.print(" min  ");                                  
    } else if (end_tim < 60 && end_tim > 0) {                     // если остался меньше минуты
        lcd.print(end_tim);
        lcd.print(" sec  ");                                      // финальный вывод завершения работы  
    } else if (end_tim <= 0) {
        final_end = 1;

	      // Конечное сообщение
        lcd.clear();
        lcd.setCursor(0, 1);
        lcd.print("   END OF SESSION ");
        lcd.setCursor(0, 2);
        lcd.print("    PRESS <Reset>  ");
        
	      // Светодиод синим
	      digitalWrite(light_pin_red, LOW);
        digitalWrite(light_pin_green, LOW);
        digitalWrite(light_pin_blue, HIGH);
    }
}

// Печатает в режиме паузы остаток времени
void time_rest() {
    tim   =  millis();  // сколько прошло с момента включения (мс)
    end_tim = (last_time - tim)/1000; // сколько осталось (с)
    lcd.setCursor(0, 2);  //  Устанавливаем курсор в позицию (0 столбец, 1 строка).
    lcd.print(" Time Rest: ");
      if (s_last_time >= end_tim && end_tim >= 7200){   // если осталось от 7 до 2 часов    
        lcd.print(end_tim / 3600);
        lcd.print(" hours ");                                      
    } else if (end_tim < 7200 && end_tim >= 3600) {     // если остался 1 час
        lcd.print(end_tim / 3600);
        lcd.print(" hour ");                                  
    } else if (end_tim < 3600 && end_tim >= 60) {       // если остался меньше часа
        lcd.print(end_tim / 60);
        lcd.print(" min ");                                  
    } else {                                            // если остался меньше минуты
        lcd.print(end_tim);
        lcd.print(" sec ");                             // финальный вывод завершения работы  
    }
}

// Функция вывода реального времени
void real_time(){
  DateTime now = rtc.now();
  lcd.setCursor(0, 0);
  lcd.print("    ");
  lcd.print(now.hour());
  lcd.print(':');
  lcd.print(now.minute());
  lcd.print(':');
  lcd.print(now.second());
  lcd.print(", ");
  lcd.print(daysOfTheWeek[now.dayOfTheWeek()]);
  lcd.print("  ");
}

// Расчатка в режиме паузы
void draw_pause(){
    lcd.setCursor(0, 1);
    lcd.print("      <PAUSE>      ");
    lcd.setCursor(0, 2);
    lcd.print("                    ");
    time_rest();
    lcd.setCursor(0, 3);
    lcd.print("                    ");
}

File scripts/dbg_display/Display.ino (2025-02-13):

#include <Wire.h>                          //  Подключаем библиотеку для работы с шиной I2C
#include <LiquidCrystal_I2C.h>             //  Подключаем библиотеку для работы с LCD дисплеем по шине I2C
LiquidCrystal_I2C lcd(0x27,16,2);          //  Объявляем  объект библиотеки, указывая параметры дисплея (адрес I2C = 0x27, количество столбцов = 16, количество строк = 2)
                                           //
uint8_t  tim_D, tim_H, tim_M, tim_S;       //  Объявляем  переменные для хранения дней, часов, минут и секунд.
uint32_t tim;                              //  Объявляем  переменную для хранения общего количества времени прошедшего после старта.
                                           //  Если надпись не появилась, замените адрес 0x27 на 0x3F
void setup(){                              //
    lcd.init();                            //  Инициируем работу с LCD дисплеем
    lcd.backlight();                       //  Включаем подсветку LCD дисплея
}                                          //
                                           //
void loop(){                               //
//  Получаем время прошедшее после старта: //
    tim   =  millis()   / 1000;            //  Получаем общее количество секунд (максимум 4'294'967 сек ≈ 49,7 дней).
    tim_S =  tim        % 60;              //  Получаем секунды: остаток от деления всех секунд на минуту (60 сек).
    tim   = (tim-tim_S) / 60;              //  Получаем общее количество минут.
    tim_M =  tim        % 60;              //  Получаем минуты: остаток от деления всех минут на час (60 мин).
    tim   = (tim-tim_M) / 60;              //  Получаем общее количество часов.
    tim_H =  tim        % 24;              //  Получаем часы: остаток от деления всех часов на день (24 час).
    tim_D = (tim-tim_H) / 24;              //  Получаем общее количество дней.
//  Выводим время прошедшее после старта:  //
    if (millis()%1000<100){                //  Условие выполняется в течении 100 первых миллисекунд каждой новой секунды.
        delay(100);  lcd.setCursor(0, 0);  //  Устанавливаем курсор в позицию (0 столбец, 0 строка).
                     lcd.print("Days: ");  //  Выводим текст.
        if(tim_D<10){lcd.print( 0      );} //  Выводим 0 перед количеством дней.
                     lcd.print(tim_D   );  //  Выводим количество дней.
                     lcd.setCursor(0, 1);  //  Устанавливаем курсор в позицию (0 столбец, 1 строка)
                     lcd.print("Time: ");  //  Выводим текст.
        if(tim_H<10){lcd.print( 0      );} //  Выводим 0 перед количеством часов.
                     lcd.print(tim_H   );  //  Выводим количество часов.
                     lcd.print(':'     );  //  Выводим символ.
        if(tim_M<10){lcd.print( 0      );} //  Выводим 0 перед количеством минут.
                     lcd.print(tim_M   );  //  Выводим количество минут.
                     lcd.print(':'     );  //  Выводим символ.
        if(tim_S<10){lcd.print( 0      );} //  Выводим 0 перед количеством секунд.
                     lcd.print(tim_S   );  //  Выводим количество секунд.
    }                                      //
}                                          //

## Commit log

2025-02-07 schemes & code & descr v3
    [scheme_arduino.fzz]
2025-02-18 add stl box
    [корпус.SLDPRT, корпус.STL, крышка.SLDPRT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]
2025-02-20 fix bug in script, change scheme
    [main.ino]
2025-02-21 Add plate & change pins in script
    [scheme.kicad_pcb, scheme.kicad_sch, корпус_large.SLDPRT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]
2025-02-22 Change scheme
    [scheme.kicad_pcb, scheme.kicad_sch, scheme_arduino.fzz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]
2025-03-05 Add new versions of boxes, update readme
    [box_1.5x_holes.SLDPRT, box_1.5x_holes.STL, box_buttons.SLDPRT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]
2025-03-05 try to view stl file
2025-03-14 Add photos, and refactor code
    [scheme_arduino.fzz]
2025-03-15 Add laser
